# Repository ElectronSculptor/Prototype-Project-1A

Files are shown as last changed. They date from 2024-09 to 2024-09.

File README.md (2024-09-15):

# Variable Distance Digital Code Lock

This project involves designing a contactless, proximity-based digital code lock system that uses capacitive sensors to detect the distance of a user’s hand from the sensors. The lock system supports complex, multi-position authentication codes that enhance security while maintaining hygiene by eliminating physical contact.

## Date

- September 15, 2024

## Project Objectives

The goal of the project was to address the limitations of traditional digital code locks, such as susceptibility to code theft through button wear and the potential transmission of bacteria. This new system offers:
- **Improved Security**: The system allows for more complex combinations by detecting the proximity of the user's hand to sensors, making it harder to steal access codes.
- **Hygiene**: A contactless interface reduces the risk of transmitting diseases.
- **Intuitiveness**: The system is easy to use with a simple, natural interface.

## Key Components

### 1. Capacitive Sensors
The system uses capacitive sensors to detect proximity and distinguish between two positions: near and far.

### 2. Signal Conditioning Circuit
The conditioner processes signals from the sensors using:
- Constant current charging for accurate capacitance measurement.
- An oscillator with a hysteresis comparator to detect the proximity threshold.

### 3. STM32 Microcontroller
An STM32 microcontroller handles the acquisition and processing of capacitance signals, converting them into digital data and determining combinations of sensor inputs.

### 4. PCB Design
The project’s electronics were designed using KiCAD to create a printed circuit board (PCB) integrating the sensors, microcontroller, and related components.

## System Architecture

1. **Capacitive Sensors**: Detect hand proximity in two positions (near/far).
2. **Conditioner**: A signal conditioner charges the capacitors and measures the charging time to deduce proximity.
3. **STM32 Microcontroller**: Handles the signal acquisition and processes input data for the multi-position code lock system.

## Testing and Results

- Testing was performed using the designed conditioners and the STM32.
- The system successfully detected two positions (near and far) and responded by lighting up LEDs in different colors to confirm the correct hand position.
- A servo motor was used as the final actuator to simulate opening a door.

## Challenges and Solutions

### PCB Design Issues
- The initial PCB design could not be fully tested due to a shortage of components.
- A revised routing method using pre-made conditioners was adopted to address manufacturing issues.

### Signal Acquisition
- Various issues were encountered with signal acquisition due to UART configuration, which was solved by using alternative UART ports.

## Conclusion

Although some objectives were not fully achieved due to technical difficulties, the project demonstrates significant progress in creating a secure, intuitive, and contactless digital code lock. Further improvements can be made in:
- Optimizing the conditioner for better detection range.
- Enhancing the user interface for ease of use.
- Expanding the application to other access control systems.

## Appendices

1. **Capacitor Code for PartQuest Simulation**
2. **STM32 Microcontroller Code**
3. **Demonstrations and Additional Calculations**

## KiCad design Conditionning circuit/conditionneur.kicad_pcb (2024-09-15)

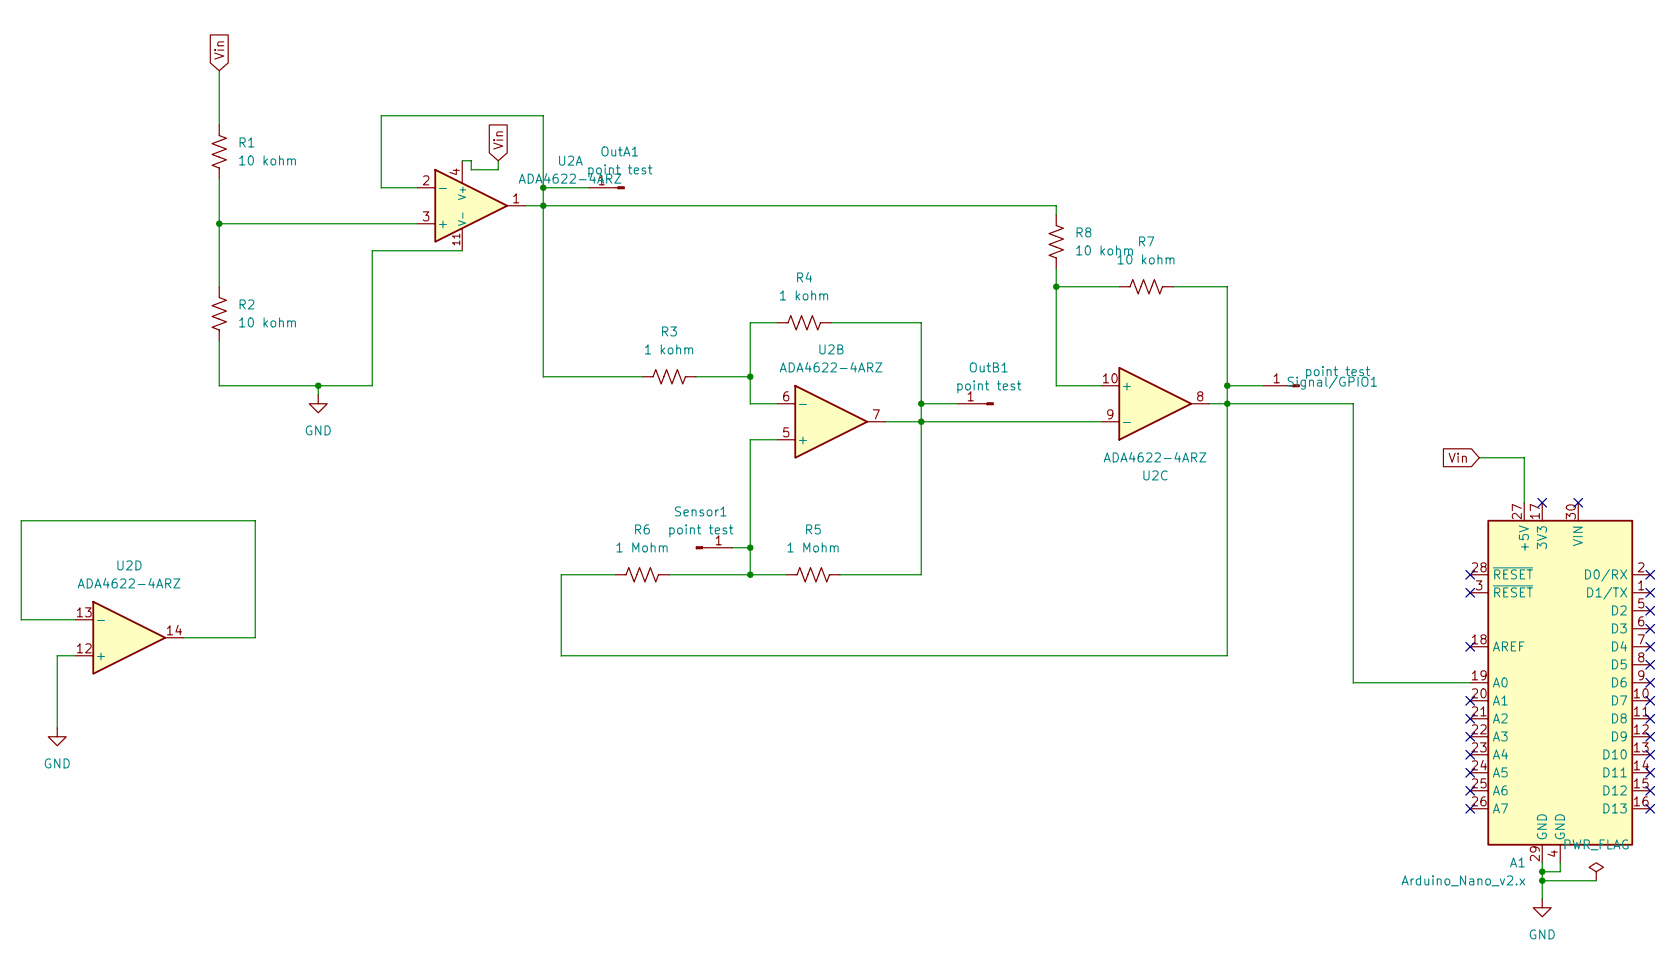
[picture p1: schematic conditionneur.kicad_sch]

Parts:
A1: Arduino_Nano_v2.x; Arduino_Nano
OutA1: point test; PinHeader_1x01_P2.54mm_Vertical
OutB1: point test; PinHeader_1x01_P2.54mm_Vertical
R1, R2, R7, R8: 10 kohm; R_0805_2012Metric_Pad1.20x1.40mm_HandSolder
R3, R4: 1 kohm; R_0805_2012Metric_Pad1.20x1.40mm_HandSolder
R5, R6: 1 Mohm; R_0805_2012Metric_Pad1.20x1.40mm_HandSolder
Sensor1: point test; PinHeader_1x01_P2.54mm_Vertical
Signal/GPIO1: point test; PinHeader_1x01_P2.54mm_Vertical
U2: ADA4622-4ARZ; SOIC-14_3.9x8.7mm_P1.27mm

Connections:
GND: A1.4 (GND), A1.29 (GND), R2.2, U2.11 (V-), U2.12 (+)
unnamed: A1.19 (A0), R6.2, R7.1, Signal/GPIO1.1, U2.8
unnamed: OutA1.1, R3.2, R8.1, U2.1, U2.2 (-)
unnamed: OutB1.1, R4.1, R5.1, U2.7, U2.9 (-)
unnamed: R5.2, R6.1, Sensor1.1, U2.5 (+)
unnamed: R1.2, R2.1, U2.3 (+)
unnamed: R3.1, R4.2, U2.6 (-)
unnamed: R7.2, R8.2, U2.10 (+)
unnamed: U2.13 (-), U2.14
Vin: A1.27 (+5V), R1.1, U2.4 (V+)

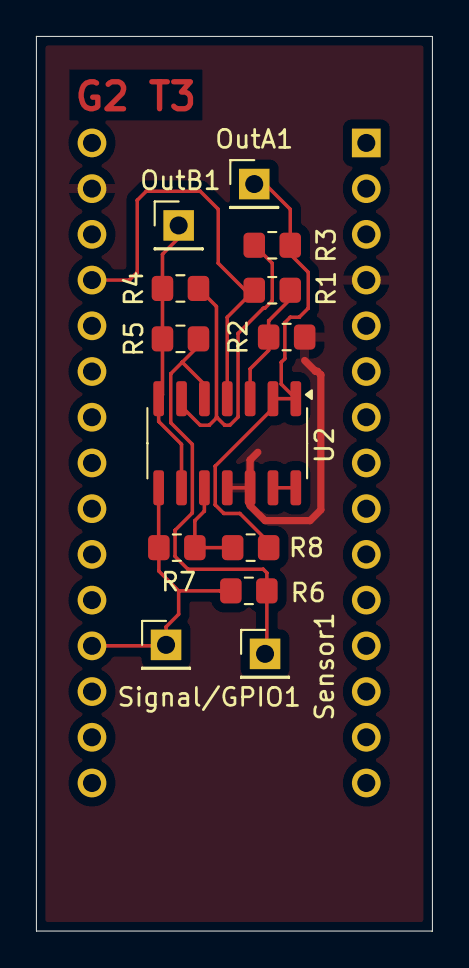
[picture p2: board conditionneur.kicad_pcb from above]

Board: 2 copper layers, 22.0 x 49.7 mm, 14 parts (1 on the bottom side), 10 nets.

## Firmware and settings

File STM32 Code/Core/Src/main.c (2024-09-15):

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
/* Includes ------------------------------------------------------------------*/
#include "main.h"

/* USER CODE BEGIN Includes */
#include "stdio.h"
/* USER CODE END Includes */

TIM_HandleTypeDef htim2;

UART_HandleTypeDef huart2;

/* USER CODE BEGIN PV */


volatile uint32_t Timer_clock = 32; // La fréquence de notre Timer en MHz
volatile int R6 = 1; // Résistance 6 du conditionneur en MegaOhm



// --------- FAIRE LES CALCULS DANS LE CALLBACK ----------- //



//Pour electrode 1
volatile int CalculOK_1;
volatile float Diff_moy_1;
volatile float IC_Valeur1_1;
volatile float IC_Valeur2_1;
volatile int Premiere_capture_1;
//Pour moyenner les valeurs electrode 1
volatile float n_1 = 0;
volatile float Freq_moy_1 = 0;
volatile float Etat_distance_1;
volatile float Capacite_moy_1; // La valeur de la Capacit 1


//Pour electrode 2
volatile int CalculOK_2;
volatile float Diff_moy_2;
volatile float IC_Valeur1_2;
volatile float IC_Valeur2_2;
volatile int Premiere_capture_2;
//Pour moyenner les valeurs electrode 2
volatile float n_2 = 0;
volatile float Freq_moy_2 = 0;
volatile float Etat_distance_2;
volatile float Capacite_moy_2; // La valeur de la Capacit 2


//Pour electrode 3
volatile int CalculOK_3;
volatile float Diff_moy_3;
volatile float IC_Valeur1_3;
volatile float IC_Valeur2_3;
volatile int Premiere_capture_3;
//Pour moyenner les valeurs electrode 3
volatile float n_3 = 0;
volatile float Freq_moy_3 = 0;
volatile float Etat_distance_3;
volatile float Capacite_moy_3; // La valeur de la Capacit 3



// On initialise la valeur de cap_data, pour le formater
uint8_t cap_data_1[5000] = {'\0'};
uint8_t cap_data_2[5000] = {'\0'};
uint8_t cap_data_3[5000] = {'\0'};



/* USER CODE END PV */

void SystemClock_Config(void);
static void MX_GPIO_Init(void);
static void MX_TIM2_Init(void);
static void MX_USART2_UART_Init(void);
/**
  * @brief  The application entry point.
  * @retval int
  */
int main(void)
{

  /* MCU Configuration--------------------------------------------------------*/

  /* Reset of all peripherals, Initializes the Flash interface and the Systick. */
  HAL_Init();

  /* Configure the system clock */
  SystemClock_Config();

  /* Initialize all configured peripherals */
  MX_GPIO_Init();
  MX_TIM2_Init();
  MX_USART2_UART_Init();
  /* USER CODE BEGIN 2 */
  HAL_TIM_IC_Start_IT(&htim2, TIM_CHANNEL_1);
  /* USER CODE END 2 */

  /* Infinite loop */
  /* USER CODE BEGIN WHILE */
  while (1)
  {
    /* USER CODE END WHILE */

    /* USER CODE BEGIN 3 */
	  if (Etat_distance_1){
		  HAL_GPIO_WritePin(LED_ROUGE_D4_GPIO_Port, LED_ROUGE_D4_Pin, GPIO_PIN_SET);
		  HAL_GPIO_WritePin(LED_BLEU_D5_GPIO_Port, LED_BLEU_D5_Pin, GPIO_PIN_RESET);
	  }
	  else{
		  HAL_GPIO_WritePin(LED_ROUGE_D4_GPIO_Port, LED_ROUGE_D4_Pin, GPIO_PIN_RESET);
		  HAL_GPIO_WritePin(LED_BLEU_D5_GPIO_Port, LED_BLEU_D5_Pin, GPIO_PIN_SET);
	  }
  }
  /* USER CODE END 3 */
}

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
/* USER CODE BEGIN 4 */



//HAL_UART_Transmit(&huart2, 'Test', 10*sizeof(char), 200);

void HAL_TIM_IC_CaptureCallback(TIM_HandleTypeDef*htim2){
	if ((htim2->Channel == HAL_TIM_ACTIVE_CHANNEL_1))
	{
		if (Premiere_capture_1 ==0)
		{
			IC_Valeur1_1 = HAL_TIM_ReadCapturedValue(htim2, TIM_CHANNEL_1);
			Premiere_capture_1 =1;
		}
		else if (Premiere_capture_1)
		{
			n_1 ++;
			if(n_1 == 10){
				IC_Valeur2_1 = HAL_TIM_ReadCapturedValue(htim2, TIM_CHANNEL_1);
				if (IC_Valeur2_1 > IC_Valeur1_1)
				{
					Diff_moy_1 = (IC_Valeur2_1 - IC_Valeur1_1)/n_1;
					Freq_moy_1= HAL_RCC_GetPCLK1Freq()/Diff_moy_1; // Frequence en Hz
					CalculOK_1 =1;

					// Calcul de la valeur de la capa en pF
					Capacite_moy_1 = 1000000/(Freq_moy_1*R6); // En Pico PicoFarad

					if (Capacite_moy_1 > 31){
						Etat_distance_1 = 1;
					}
					else{
						Etat_distance_1 = 0;
					}

					// Envoyer les valeurs dans le UART
					sprintf(cap_data_1, "Frequence = %f Hz , Capacite = %f pF , Seuil = %d \n\r", Freq_moy_1, Capacite_moy_1, Etat_distance_1);
					HAL_UART_Transmit(&huart2, cap_data_1, sizeof(cap_data_1), 200);
					n_1 = 0;
				}
				else
					CalculOK_1 =0;
				Premiere_capture_1 = 0;


			}

		}
	}
}


/* USER CODE END 4 */
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


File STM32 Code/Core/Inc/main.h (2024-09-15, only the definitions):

#define LED_VERT_D6_Pin GPIO_PIN_1
#define LED_VERT_D6_GPIO_Port GPIOB
#define LED_BLEU_D5_Pin GPIO_PIN_6
#define LED_BLEU_D5_GPIO_Port GPIOB
#define LED_ROUGE_D4_Pin GPIO_PIN_7
#define LED_ROUGE_D4_GPIO_Port GPIOB

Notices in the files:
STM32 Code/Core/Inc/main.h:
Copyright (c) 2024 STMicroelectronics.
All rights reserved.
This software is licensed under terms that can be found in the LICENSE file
